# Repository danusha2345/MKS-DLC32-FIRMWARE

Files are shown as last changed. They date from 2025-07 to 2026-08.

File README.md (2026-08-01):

# MKS-DLC32-FIRMWARE — CNC-форк с TMC2209 по UART


Прошивка контроллера **MKS DLC32 v2.1** (ESP32) для ЧПУ-станка со шпинделем:
**без экрана**, с драйверами **TMC2209 в UART-режиме** — ток, микрошаг и тихий
StealthChop настраиваются командами по USB/Wi-Fi, без перемычек и подстроечников.

Форк ветки `MKS-DLC32-NEW-CNC` от [IDLEVEL/MKS-DLC32-FIRMWARE](https://github.com/IDLEVEL/MKS-DLC32-FIRMWARE),
которая основана на брошенной официальной прошивке
[makerbase-mks/MKS-DLC32-FIRMWARE](https://github.com/makerbase-mks/MKS-DLC32-FIRMWARE)
(движок Grbl_ESP32 v1.1). Прошивка переведена на **arduino-esp32 2.0.17**
(espressif32 6.12.0, ESP-IDF 4.4.7) с серией фиксов стабильности — разбор в
[`docs/MIGRATION_6X.md`](docs/MIGRATION_6X.md), технические заметки форка — в
[`docs/FORK_NOTES.md`](docs/FORK_NOTES.md).

## Конфигурация этой ветки

- **Экран не используется.** Станок управляется по USB, Telnet, WebUI в браузере
  или Android-приложением — панель TS35 в этой конфигурации не нужна.
- **TMC2209 по UART**: общая шина на пинах разъёма I2C платы. Из-за этого:
  - выходы **coolant M7/M8 недоступны** (их пины заняты шиной);
  - **внешний пульт IDLEVEL несовместим** с этим вариантом (использует те же IO0/IO4);
  - нужна небольшая **навесная обвязка согласования уровней** (логика драйверов на
    плате пятивольтовая) — см. ниже.
- Шаги идут как обычно (step/dir через I2S-регистры): UART нужен только для
  настройки, при потере связи с драйвером движение не останавливается.

## Целевое железо

- Плата: **MKS DLC32 v2.1** — ESP32-WROOM-32U (8 МБ flash, 520 КБ RAM), степперы
  через I2S-сдвиговые регистры. Полная спека — [`docs/BOARD_SPEC.md`](docs/BOARD_SPEC.md).
- Драйверы: 3× **TMC2209** (степстики) в сокетах платы.
- Назначение: **ЧПУ-фрезер** (3 оси XYZ, шпиндель с PWM).

Карта пинов задаётся в `Firmware/Grbl_Esp32/src/Machines/i2s_out_xyz_mks_dlc32.h`
(флаги `USE_BOARD_V2_0` + `USR_Z_MOTOR` + `USE_TMC2209_UART`):

| Функция | Пин |
|---|---|
| Шпиндель PWM | GPIO32 |
| Probe | GPIO22 |
| Концевики X / Y / Z | GPIO36 / GPIO35 / GPIO34 |
| Степперы X/Y/Z (step/dir) | I2S (BCK16 / WS17 / DATA21) |
| Шина TMC2209 UART | TX=IO0, RX=IO4 (пины разъёма I2C) |
| SD-карта | SPI: SCK14, MISO12, MOSI13, CS15; детект GPIO39 |

Все 3 оси полноценные (движение/джоггинг/probe/обнуление по Z работают).
Авто-хоминг по Z выключен в дефолтах (`$22=0`) — включается через настройки или
`DEFAULT_HOMING_ENABLE 1` + `DEFAULT_HOMING_CYCLE_1 (bit(Z_AXIS))`.

## TMC2209: подключение и настройка

Коротко (полная инструкция с номиналами и граблями —
[`docs/TMC2209_UART.md`](docs/TMC2209_UART.md)):

- ⚠️ **Напрямую проводом подключать нельзя.** На DLC32 логика шаговой части
  пятивольтовая: VIO степстика (пин 7 сокета) жёстко разведён на **+5V**,
  step/dir/en приходят с 74HC595, запитанного 5 В, а EN ещё и подтянут к +5V
  резисторами R31–R33. У TMC2209 порог «1» равен `0.7 × VIO` = **3.5 В** (3.3 В
  с ESP32 недостаточно), а отвечает он уровнем VIO = 5 В — прямо в GPIO ESP32,
  у которого абсолютный максимум ~3.6 В. Нужен преобразователь уровней на одной
  UART-линии: два копеечных буфера с фиксированным направлением (`SN74AHCT1G125`
  с питанием 5 В на TX и `SN74LVC1G17` с питанием 3.3 В на RX — у последнего вход
  толерантен к 5.5 В), либо один `TXU0202`. Плату при этом переделывать не надо.
  Разбор всех вариантов (в том числе почему не годится «перевести VIO на 3.3 В»
  и почему нельзя понизить сам источник 5 В) —
  в [`docs/TMC2209_UART.md`](docs/TMC2209_UART.md).

  ```text
  разъём I2C DLC32                                       общая линия PDN_UART
  (1=+3V3, 2=GND, 3=SDA=IO0, 4=SCL=IO4)
                     ┌────────────────────────┐
   SDA = IO0 (TX) ──►│ SN74AHCT1G125, VCC=+5В │──[1 кОм]──┐
                     │ OE# → GND              │           │
                     └────────────────────────┘           ├───────┬────────┬────────┐
                     ┌────────────────────────┐           │       │        │        │
   SCL = IO4 (RX) ◄──│ SN74LVC1G17, VCC=+3.3В │◄──────────┘   PDN_UART PDN_UART PDN_UART
                     └────────────────────────┘               модуль X модуль Y модуль Z
   GND ── общий                                               (пины RST/SLP сокета)
   +5 В для обвязки — с EXP1 (пин 10), экран не используется
  ```

  На разъёме I2C пин питания — **+3V3, не 5 В**; подключать его никуда не нужно.
- PDN_UART у степстиков SilentStepStick v2.0 выведен на позиции сокета
  **RST/SLP**, а DLC32 соединяет эти два пина между собой и больше никуда —
  провод шины паяется прямо к площадке сокета, ножки отгибать не нужно.
- Шина одна на все три драйвера: адрес получателя прошивка вписывает в каждый
  пакет. Адрес задаётся пинами **MS1/MS2** (в UART-режиме это адресные биты, а не
  микрошаг), которые на DLC32 выведены на штатные DIP-переключатели:

  | Драйвер в сокете | Адрес | Поз. 1 (MS1) | Поз. 2 (MS2) | Поз. 3 |
  |---|---|---|---|---|
  | X (`SW1`) | 0 | OFF | OFF | OFF |
  | Y (`SW2`) | 1 | **ON** | OFF | OFF |
  | Z (`SW3`) | 2 | OFF | **ON** | OFF |

  Позиция 3 — это не MS3, а **SPREAD**: включённая даст SpreadCycle вместо
  StealthChop, держать OFF.

  Принадлежность мотора к оси задаёт **сокет** (step/dir), адрес — только кому
  уйдут настройки тока/микрошага. Перепутанный адрес не поменяет оси местами,
  но настройки «для X» молча применятся к чужому мотору, поэтому: драйвер в
  сокете X обвязывается на адрес 0, в Y — 1, в Z — 2. Два одинаковых адреса =
  оба молчат (CRC-ошибки), прошивка сообщит при старте. Проверка раскладки:
  `$X/Current/Run=0.1` → момент должен потерять именно X-мотор; повторить для Y/Z.
- Настройки в прошивке: ток `$X/Current/Run` (серия `$140`), удержание
  `$X/Current/Hold` (`$150`), микрошаг `$X/Microsteps` (`$160`) — аналогично Y/Z.
  Хранятся в NVS, применяются сразу: можно менять хоть перед каждым заданием.
  `$X/Current/Run=0` отключает выход драйвера (TOFF=0); микрошаг принимается
  только из ряда 0/2/4/8/16/32/64/128/256.
- Режим — StealthChop (тихий), задан на этапе компиляции.
- При старте прошивка проверяет связь с каждым драйвером и пишет результат в
  консоль; предупреждает о short-to-ground и перегреве.

> ⚠️ Вариант TMC2209 UART собран и проверен компиляцией, но **на живом станке
> ещё не гонялся** — базовой прошивки это не касается.

## Сборка

Нужен [PlatformIO Core](https://platformio.org/) (или расширение PlatformIO в VS Code).

```bash
cd Firmware
pio run -e mks_dlc32_v2_1_tmc            # сборка TMC-варианта
pio run -e mks_dlc32_v2_1_tmc -t upload  # прошивка по USB
```

Артефакт: `Firmware/.pio/build/mks_dlc32_v2_1_tmc/firmware.bin`.

Окружения (`Firmware/platformio.ini` + `Firmware/ini/mks_dlc32.ini`):

| env | Назначение |
|---|---|
| `mks_dlc32_v2_1_tmc` | **Основное для этой ветки**: TMC2209 по UART. Партиция `esp32_8MiB.csv` (2× OTA-слота по 3 МБ) |
| `mks_dlc32_v2_1` | Базовый вариант без TMC UART (драйверы в обычном step/dir-режиме, coolant на месте) |
| `mks_dlc32_v2_1_ota` | Загрузка по воздуху (espota, IP в `ini/mks_dlc32.ini`). ⚠️ Собирает **базовый** вариант — для OTA TMC-варианта добавьте в env флаг `-D USE_TMC2209_UART` |

Готовые бинарники в [`release/`](release/) (со скриптами `flash_usb.sh`/`.bat`)
тоже собраны из **базового** варианта — TMC-вариант собирайте из исходников.

## Тесты

Чистую логику (без зависимостей от железа) покрываем нативными unit-тестами:

```bash
cd Firmware
pio test -e native
```

Тесты лежат в `Firmware/test/`, чистая логика — в модулях без зависимостей от
железа, чтобы её можно было гонять нативно:

| Модуль | Тесты | Что покрыто |
|---|---|---|
| `src/SDJobPolicy.cpp` | `test_sd_job_policy` | политика «SD-печать + команды со второго интерфейса» |
| `src/SDLineReader.cpp` | `test_sd_line_reader` | разбор строки G-кода: границы буфера, EOF, ошибка чтения |
| `src/Motors/TrinamicSettings.cpp` | `test_trinamic_settings` | микрошаг вне ряда, деление на ноль в `calc_tstep`, нулевой ток |

Всего 23 теста. Драйверы и `readFileLine` остаются тонкими обёртками над этими
модулями — железо в тестах не участвует.

## Статус

Базовая функциональность **проверена на реальной плате MKS DLC32 v2.1**
(ESP32-D0WD, flash 8 МБ) — протокол испытаний в
[`docs/CODE_REVIEW.md`](docs/CODE_REVIEW.md). Проверка велась на голой плате
(USB): пункты, требующие собранного станка — лимиты/хоминг/движение/джоггинг/
probe/SD-печать со «Стоп» — собраны в
[`docs/MIGRATION_6X.md`](docs/MIGRATION_6X.md#-что-надо-протестировать-на-железе).

- ✅ Собирается на Linux/Mac/Windows.
- ✅ Wi-Fi: событийный авто-реконнект STA, self-heal из AP-fallback, mDNS в AP и
  STA (`http://mks-dlc32.local`). Сеть — WPA2 2.4 ГГц (WPA3-only ESP32 не умеет).
  Ping-soak 60 c = 0% потерь.
- ✅ OTA по воздуху: партиция под реальные 8 МБ, два app-слота по 3 МБ.
- ✅ SD ↔ USB/сеть: во время задания с карты со второго интерфейса проходят
  realtime и read-only запросы (`?`, `$$`, `$G`…), движение отклоняется
  `error:120` **без обрыва задания**.
- ✅ WebUI: канал WebUI↔ядро жив, большие ответы не теряются; имя устройства
  `mks-dlc32`, меняется в WebUI.
- ✅ Telnet, HTTP-загрузка файлов на SD (`/upload`). Карта — только FAT32
  (exFAT не монтируется — карты >32 ГБ переформатировать). Во время задания с SD
  загрузка нового файла намеренно блокируется — заливать до запуска.
- ✅ Удалённое управление через центральный сервер: плата сама подключается к
  нему по TCP (`$Remote/Server`, `$Remote/Token`, `$Remote/Name`, хранятся в
  NVS) — инструкция в [`docs/REMOTE_CONTROL.md`](docs/REMOTE_CONTROL.md).
- ✅ SD-задание честно сообщает о сбое: слишком длинная строка (от 255 символов)
  или ошибка чтения больше не выдаются за успешное завершение; устранена запись
  за границу буфера на строке ровно в 255 символов.
- ✅ Read-only команды (`$$`, `$+`, `$L`, `$S`, `$SC`, `$CMD`) переведены на явный
  `anyState`; `$Axis/Current/Run=0` больше не программирует максимальный ток,
  микрошаг принимается только из ряда 0/2/4…256.
- ⏳ TMC2209 UART: собрано, ждёт проверки на железе (см. выше).
- 🔜 По умолчанию аутентификация выключена — смените пароль AP в WebUI.

## Лицензия

GPLv3 (наследуется от Grbl / Grbl_ESP32). См. [`LICENSE`](LICENSE).

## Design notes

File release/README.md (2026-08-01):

# Прошивка MKS DLC32 v2.1 готовыми бинарниками

Комплект для прошивки платы **без установки PlatformIO** — нужен только Python
с esptool. Версия сборки — в [`VERSION.txt`](VERSION.txt).

| Файл | Что это | Адрес во flash |
|---|---|---|
| `bootloader.bin` | Загрузчик ESP32 (DOUT, 80 МГц) | `0x1000` |
| `partitions.bin` | Таблица разделов под 8 МБ (OTA: два app-слота по 3 МБ) | `0x8000` |
| `boot_app0.bin` | Селектор OTA-слота | `0xe000` |
| `firmware.bin` | Прошивка Grbl_ESP32 + наши фиксы | `0x10000` |
| `spiffs.bin` | Файловая система с WebUI (ESP3D-WEBUI 2.1.3b0, рус./англ.) | `0x610000` |

Настройки платы (**Wi-Fi, `$$`-параметры GRBL**) при прошивке скриптами
`flash_usb.*` **сохраняются** — они лежат в NVS-разделе (`0x9000`), который
скрипты не трогают.

### Единый образ для чистой установки

`MKS_DLC32_full_8MB.bin` (если приложен) — все разделы в одном файле, прошивается
на адрес `0x0`:

```bash
esptool.py --chip esp32 --port /dev/ttyUSB0 --baud 921600 \
  write_flash --flash_mode dout --flash_freq 80m --flash_size 8MB 0x0 MKS_DLC32_full_8MB.bin
```

Удобен для веб-флешеров (ESP Web Tools, MKS Flash Tool). **Внимание:** этот образ
перезаписывает NVS → **настройки Wi-Fi сбрасываются** (плата поднимет точку доступа
`MKS_DLC`). Чтобы сохранить настройки — прошивайте раздельными bin через `flash_usb.*`.

## Подготовка (один раз)

1. **Python 3** — [python.org](https://www.python.org/downloads/) (Windows: при
   установке отметить «Add Python to PATH»).
2. **esptool**: `pip install esptool`
3. **Windows**: драйвер USB-моста [CH340](https://www.wch-ic.com/downloads/CH341SER_EXE.html).
   Номер порта смотреть в Диспетчере устройств → «Порты (COM и LPT)».
   **Linux**: пользователь должен быть в группе `dialout`
   (`sudo usermod -aG dialout $USER`, перелогиниться).

## Прошивка по USB

Подключить плату кабелем USB (питание платы 12/24 В подавать не обязательно —
для прошивки хватает USB).

**Linux/macOS:**
```bash
./flash_usb.sh                 # порт /dev/ttyUSB0
./flash_usb.sh /dev/ttyUSB1    # другой порт
```

**Windows:**
```bat
flash_usb.bat            (порт COM3)
flash_usb.bat COM5       (другой порт)
```

Если на скорости 921600 прошивка обрывается (длинный/плохой кабель), добавить
вторым аргументом `115200`.

### Полный сброс (если плата вела себя странно или стояла другая прошивка)

Стереть всё, включая настройки, затем прошить:

```bash
esptool.py --chip esp32 --port /dev/ttyUSB0 erase_flash
./flash_usb.sh
```

После этого плата поднимет точку доступа `MKS_DLC` (пароль `12345678`),
веб-интерфейс: `http://192.168.4.1`. Подключение к домашней сети — в
WebUI → Settings (сеть должна быть **WPA2, 2.4 ГГц** — WPA3-only ESP32 не умеет).

## Обновление по воздуху (OTA), когда плата уже в сети

Из дерева исходников (нужен PlatformIO):

```bash
pio run -e mks_dlc32_v2_1_ota -t upload --upload-port <IP-платы>
```

Только WebUI (SPIFFS): `pio run -e mks_dlc32_v2_1 -t uploadfs` по USB.

## Откуда взялись бинарники

Собраны из этого репозитория: `pio run -e mks_dlc32_v2_1_tmc` (+`-t buildfs` для
SPIFFS); `bootloader.bin`/`boot_app0.bin` — стандартные из arduino-esp32 1.0.6
(`bootloader_dout_80m.bin`). Адреса соответствуют тому, что пишет
`pio run -t upload` (проверено `-v`).

> ⚠️ **Это сборка варианта `mks_dlc32_v2_1_tmc`** — драйверы TMC2209 настраиваются
> по UART, экран не используется, coolant M7/M8 недоступен (его пины заняты шиной).
> Шине нужна навесная обвязка согласования уровней: логика драйверов на плате
> пятивольтовая, ESP32 — 3.3 В. Схема, номиналы и обоснование —
> [`docs/TMC2209_UART.md`](../docs/TMC2209_UART.md). **Без обвязки UART не заработает,
> а RX, заведённый напрямую, способен повредить GPIO ESP32.** Сам станок при этом
> ездит как обычно: step/dir идут через I2S и от UART не зависят.
> На живом станке эта сборка ещё не проверялась.

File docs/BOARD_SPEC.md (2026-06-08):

# MKS DLC32 v2.1 — аппаратная спецификация (справочник)

Сводка характеристик платы, вытянутая из официальных источников. Нужна как справка
при доработке прошивки (особенно по flash/OTA и связи).

## Процессор / память
- **Модуль:** ESP32-WROOM-32U (чип ESP32-D0WD-V3, Xtensa dual-core LX6, до **240 MHz**).
- **Flash: 8 МБ** (8192 КБ). ⚠️ Не 16 МБ — важно для разбивки разделов и OTA.
- **RAM:** 520 КБ SRAM.
- Беспроводь: Wi-Fi (2.4 ГГц) + Bluetooth — встроены в ESP32. **Проводного Ethernet нет.**

## Связь
- **Wi-Fi:** AP или STA, WebUI / WebSocket / Telnet / OTA / mDNS.
- **USB:** через USB-UART (CH340) — управление с ПК и прошивка. Не сеть.
- **Bluetooth:** аппаратно есть (в прошивке `ENABLE_BLUETOOTH` выкл; есть подпроект `GRBL_Bluetooth/`).
- **SD-карта:** локальное хранилище/запуск G-code.
- **Ethernet/RJ45: отсутствует.**

## Управление / экран
- 3 оси (XYZ).
- Экран: тач-TFT **MKS TS35 (3.5")** или **TS24** (V2.0).
- Драйверы шагов: **TMC2209** (штатно), также A4988 / DRV8825, поддержка внешних драйверов.
- Степперы заводятся через I2S-сдвиговые регистры (см. `i2s_out_xyz_mks_dlc32.h`).
- Выход шпинделя/лазера: PWM (в прошивке GPIO32).
- Макс. скорость перемещения: **до 8000 мм/мин**.

## Питание / габариты
- Вход: **DC 12 В или 24 В**, ток < 10 A.
- Размер платы: **90 × 70 мм**.

## Софт
- Прошивка: GRBL (Grbl_ESP32). Хосты: LightBurn, LaserGRBL, UGS и т.п.
- Управление: экран (офлайн) / WebUI / мобильное приложение.

## Версии
- Линейка: V1.0 / V2.0 / V2.1. У нас **V2.1** (в прошивке флаг `USE_BOARD_V2_0` для пин-маппинга,
  машина `MACHINE_TYPE_DEFAULT`). Есть и отдельная новая плата **DLC32 MAX** на ESP32-S3 — это другое железо.

## Следствия для прошивки (важно)
- **OTA:** при 8 МБ flash партиция `esp32_16MiB.csv` (env `mks_dlc32_v2_1_ota`) **не подходит** —
  нужна OTA-разбивка под 8 МБ (два app-раздела ~3 МБ + SPIFFS). Текущий рабочий env —
  `mks_dlc32_v2_1` (4 МБ layout, USB), и он в 8 МБ укладывается.
- Прошивка сейчас занимает Flash ~94% от ~1.79 МБ app-раздела — для OTA на 8 МБ места хватит,
  но app-раздел в OTA-схеме надо задать с запасом.

## Источники
- [makerbase-mks/MKS-DLC32 (офиц. репозиторий, hardware/доки/схемы)](https://github.com/makerbase-mks/MKS-DLC32)
- [MKS DLC32 V2.1 Offline Controller User Manual (manuals.plus)](https://manuals.plus/ae/1005004617130208)
- [MKS DLC32 V2.1 SCH.pdf — схема платы](https://github.com/makerbase-mks/MKS-DLC32/blob/main/MKS-DLC32-main/hardware/MKS%20DLC32%20V2.1_003/MKS%20DLC32%20V2.1_003%20SCH.pdf)

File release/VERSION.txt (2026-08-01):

Сборка: feat/tmc2209-uart 9eb311e, дата 2026-08-01, предрелиз v2.1-tmc-beta4
Вариант: mks_dlc32_v2_1_tmc — TMC2209 по UART, БЕЗ экрана
Прошивка: Grbl_ESP32 1.1 (2022042101) + фиксы форка danusha2345
SDK: arduino-esp32 2.0.17 (espressif32 6.12.0, ESP-IDF 4.4.7)
WebUI: ESP3D-WEBUI 2.1.3b0 (en/ru/uk/de/fr/es/it/pl/ptbr)
Плата: MKS DLC32 v2.1, ESP32-WROOM-32U, 8 МБ flash

!! ПРЕДРЕЛИЗ. На живом станке эта сборка не проверялась.
!! TMC2209 по UART требует навесной обвязки согласования уровней:
!! логика драйверов на плате пятивольтовая, ESP32 — 3.3 В.
!! Схема и номиналы: docs/TMC2209_UART.md. Без обвязки шина не заработает
!! (а RX напрямую способен повредить GPIO ESP32).

Новое в v2.1-tmc-beta4:
  - $Axis/Current/Run=0 теперь действительно отключает выход драйвера
    (TOFF=0, мосты обесточены). В beta3 писался только IRUN=IHOLD=0, что
    по даташиту TMC2209 означает минимальный ток (1/32 шкалы, ~55 мА RMS),
    а не ноль.
  - Bare-board smoke-тест на живой плате: загрузка с GPIO0-как-TX, три
    честных «driver test failed» без драйверов, SD-фиксы (TooLong/Finish/
    восстановление после сбоя), валидация Microsteps с persistence через
    ребут — PASS. С реальными драйверами и обвязкой уровней не проверялось.

Новое в v2.1-tmc-beta3 (все фиксы v1.3.0 базовой ветки + доводка):
  - SD-печать честно сообщает о сбое (TooLong/ReadError вместо ложного
    "SD Print Finish!"), нет записи за границу буфера, SD не виснет в Busy
    после выёма карты, закрыта гонка ?-статуса с закрытием файла.
  - StallGuard-хоминг не роняет плату при Microsteps=0.
  - $Axis/Microsteps: значения вне ряда 0/2/4...256 отклоняются и в NVS
    не попадают.
  - 23 нативных unit-теста.

Новое в v2.1-tmc-beta2:
  $Axis/Current/Run=0 = выключенный ток; SENDDELAY=2; разбор уровней
  TMC2209 <-> DLC32 в docs/TMC2209_UART.md.

Новое в v2.1-tmc-beta1:
  Вариант прошивки с TMC2209 по UART: ток, микрошаг и StealthChop
  настраиваются командами; шаги идут как обычно через I2S. Экран не
  используется, coolant M7/M8 недоступен (его пины заняты шиной).

Файлы:
  MKS_DLC32_full_8MB.bin  - единый образ на 0x0 (чистая установка, сброс Wi-Fi)
  firmware.bin + spiffs.bin + bootloader/partitions/boot_app0
  flash_usb.sh / flash_usb.bat - прошивка с сохранением настроек

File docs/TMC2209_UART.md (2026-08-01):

# TMC2209 в UART-режиме на MKS DLC32

Вариант прошивки `mks_dlc32_v2_1_tmc`: драйверы TMC2209 управляются шагами как обычно
(step/dir через I2S-регистр), а по UART настраиваются ток, микрошаг и StealthChop —
в любой момент, в том числе перед каждым заданием.

## Сборка и прошивка

```bash
cd Firmware
pio run -e mks_dlc32_v2_1_tmc            # сборка
pio run -e mks_dlc32_v2_1_tmc -t upload  # прошивка по USB
```

Обычный env `mks_dlc32_v2_1` не затронут: без флага `USE_TMC2209_UART` прошивка
идентична прежней (step/dir, coolant на месте).

## ⚠️ Уровни: голым проводом подключать нельзя

Это главный подводный камень варианта. Всё, что ниже, сверено с официальной схемой
[MKS DLC32 V2.1_003 SCH.pdf](https://github.com/makerbase-mks/MKS-DLC32/blob/main/MKS-DLC32-main/hardware/MKS%20DLC32%20V2.1_003/MKS%20DLC32%20V2.1_003%20SCH.pdf)
и даташитом TMC2209 (rev. 1.03).

Логическая часть шаговой обвязки DLC32 работает **на 5 В**, а ESP32 — на 3.3 В:

| Что | Напряжение | Где на схеме |
|---|---|---|
| VIO степстика (пин 7 сокета, `VDD`) | **+5V**, жёстко разведено | `DRIVE.sch`, `J24/J25/J26` |
| STEP / DIR / EN | 5 В, с 74HC595 (`U3`, VCC=+5V) через сборки RPK | `ESP32.sch` + `DRIVE.sch` |
| Подтяжки EN | на **+5V** (`R31/R32/R33`) — присутствуют всегда, даже до старта прошивки | `DRIVE.sch` |
| MS1/MS2/MS3 | DIP-переключатели коммутируют на **+5V** | `DRIVE.sch`, `SW1/SW2/SW3` |
| GPIO ESP32 | 3.3 В, абсолютный максимум ~3.6 В | `ESP32.sch` |

Из даташита TMC2209: `VINHI = 0.7 × VVIO`, то есть при VIO = 5 В порог логической «1»
равен **3.5 В** — трёх с третью вольт с ESP32 недостаточно по спецификации. А PDN_UART
описан как «I/O with Schmitt Trigger and **VCC_IO level**», то есть ответ драйвера
идёт уровнем 5 В — прямо в GPIO ESP32, чего тот не переживёт.

Итог: **нужен преобразователь уровней на UART-линии.** Одна логическая микросхема и
три резистора — переделывать саму плату не нужно.

### Схема согласования

Два однобитных буфера с фиксированным направлением — по одному на каждую сторону
полудуплексной линии:

```text
разъём I2C DLC32               навесная обвязка                общая линия PDN_UART
(пины: 1=+3V3, 2=GND,
 3=SDA=IO0, 4=SCL=IO4)
                       ┌───────────────────────┐
  SDA (IO0, TX) ──────►│ SN74AHCT1G125, VCC=+5В│──[1 кОм]──┐
                       │ OE# → GND             │           │
                       └───────────────────────┘           ├────┬────────┬────────┐
                       ┌───────────────────────┐           │    │        │        │
  SCL (IO4, RX) ◄──────│ SN74LVC1G17, VCC=+3.3В│◄──────────┘ PDN_UART PDN_UART PDN_UART
                       └───────────────────────┘             модуль X модуль Y модуль Z
  GND ── общий с платой и с обвязкой                        (пины RST/SLP сокета)
  по 100 нФ на каждое питание, рядом с корпусом
```

- **TX: `SN74AHCT1G125`** (SOT-23-5) питается от **+5 В**: у HCT-логики порог входа
  ~1.3 В, поэтому 3.3 В с ESP32 — уверенная «1», а на выходе получаются честные 5 В для
  входа TMC2209. `OE#` (пин 1) на GND. Такой буфер прямо предложен даташитом TMC2209
  (Fig. 4.2, «optional buffer for … many slaves»).
- **Резистор 1 кОм** — как в даташите (Fig. 4.1): мастер держит линию постоянно, и когда
  драйвер отвечает нулём, резистор ограничивает встречный ток (5 В / 1 кОм = 5 мА). Если
  связь с тремя драйверами неустойчива — уменьшить до ~470 Ом.
- **RX: `SN74LVC1G17`** (Schmitt-буфер, SOT-23-5) питается от **+3.3 В**, но его вход
  толерантен к 5.5 В — то есть принимает пятивольтовый ответ драйвера и отдаёт чистые
  3.3 В в ESP32. Резистивный делитель тут хуже: он вешает на шину лишнюю нагрузку на
  землю и заваливает фронты.
- **Питание обвязки**: экран в этой ветке не используется, поэтому свободен разъём
  **EXP1: пин 10 = +5V, пин 9 = GND** (`P-AUX.sch`). +3.3 В — пин 1 разъёма I2C или
  пин 10 EXP2. Альтернатива для 5 В — пин 7 (VDD) любого степстик-сокета.

**Однокристальная альтернатива — `TXU0202`** (TI): два канала с фиксированными встречными
направлениями, dual-rail 3.3 / 5 В, push-pull выходы, Schmitt-входы. Подключение то же:
`A1←TX`, `B1─[1 кОм]→линия`, `B2←линия`, `A2→RX`, `OE` на 3.3 В, по 100 нФ на VCCA и VCCB.
Брать корпус **VSSOP (суффикс DCU)** — варианты X2SON/X1QFN вручную не паяются. Учесть,
что у TXU0202 на входах есть внутренние pull-down: пока VCCA/OE не поднялись, линия PDN
провисает в ноль (для драйверов это штатный standstill current reduction, но до первого
пакета они будут в нём). У пары 1G125 + 1G17 линия встаёт в idle-high сразу с питанием.
- ⚠️ **На разъёме I2C пин питания — +3V3, а не 5 В** (по схеме `J2` пин 1 = `+3V3`).
  Для питания буфера он не годится, и вообще на этот разъём ничего подавать не нужно.

### Почему нельзя «просто перевести VIO драйверов на 3.3 В»

Абсолютный максимум цифрового входа TMC2209 — `VVIO + 0.5 В`. Если сделать VIO = 3.3 В,
то EN, STEP и DIR (все они пятивольтовые, см. таблицу выше) начнут пробивать защитные
диоды внутрь шины VIO. На EN ток потечёт **постоянно**, из-за подтяжки R31 на +5 В — она
неотключаемая. Насколько быстро это убьёт драйвер, зависит от номинала сборок RPK.

Чтобы этот путь заработал, пришлось бы отогнуть у каждого модуля VDD, EN, STEP и DIR
(12 ножек на три оси) и подать сигналы через понижающий буфер 74LVC245 — то есть намного
больше работы, чем один вентиль на одном проводе.

### Почему нельзя понизить сам источник 5 В

Тоже нет: на DLC32 3.3 В **делаются из 5 В**. Бука `U4` даёт +5V, из него LDO `U5`
получает +3V3 для ESP32 (`POWER.sch`). Понизив +5V, получим LDO в dropout и мёртвый
ESP32. А закоротить LDO нельзя, потому что при питании от USB 5 В приходит на тот же
рейл в обход буки (`U5V → D3 → +5V`) — при первом подключении кабеля 5 В попадут на
ESP32. Плюс от +5V питаются разъёмы концевиков `J9…J12` (для активных датчиков).

Теоретически возможен третий путь — **локальный 3.3-вольтовый домен**: перекинуть на
+3V3 питание `U3` (пины 16 и 10), VDD трёх сокетов, верхние концы `R31…R33` и общий
провод DIP-переключателей. Тогда весь тракт становится 3.3-вольтовым и UART подключается
напрямую. Но это 7–8 точек SMD-хирургии, необратимо, и надо иметь в виду, что BCK шины
I2S здесь 8 МГц (`I2S_OUT_USEC_PER_PULSE = 4` мкс на 32-битный кадр) — у 74HC595 при
питании 3.3 В запас по частоте перестаёт быть многократным.

## Проводка

UART-шина сидит на пинах **разъёма I2C** платы (паяться к ESP32 не нужно):

| Сигнал | Пин ESP32 | Куда |
|---|---|---|
| TX | IO0 (пин 3 разъёма I2C, шелкография `SDA`) | на вход буфера 74AHCT1G125 |
| RX | IO4 (пин 4 разъёма I2C, шелкография `SCL`) | на среднюю точку делителя 10к/20к |
| GND | пин 2 разъёма I2C | общий с обвязкой (с драйверами уже общий через плату) |

Перед пайкой прозвонить разъём: пин с шелкографией **SDA** должен звониться на
GPIO0 модуля ESP32, **SCL** — на GPIO4 (в прошивке `IIC_SDA=0`, `IIC_SCL=4`).

**Куда паять PDN_UART.** У степстиков SilentStepStick TMC2209 v2.0 (Watterott, FYSETC и
клоны) PDN_UART выведен на **две позиции сокета — `RST` и `SLP`** (пины 12 и 11), выбор
джампером на модуле. На DLC32 эти два пина сокета **соединены между собой и больше
никуда не идут** — изолированный островок. Поэтому провод шины паяется прямо к площадке
`RST`/`SLP` сокета, **ножки модулей отгибать не нужно**.

У модулей BTT (TMC2209 v1.2 и родня) разводка своя — там отдельный UART-пятак на плате
модуля; проверить прозвонкой и паять к нему.

## Адреса драйверов (штатными DIP-переключателями)

В UART-режиме MS1/MS2 задают не микрошаг, а адрес на шине. На DLC32 они выведены на
DIP-переключатели `SW1` (X), `SW2` (Y), `SW3` (Z), которые коммутируют их на +5 В = VIO —
то есть адреса выставляются переключателями, ничего допаивать не нужно:

| Ось | Адрес | Поз. 1 (MS1) | Поз. 2 (MS2) | Поз. 3 |
|---|---|---|---|---|
| X | 0 | OFF | OFF | OFF |
| Y | 1 | **ON** | OFF | OFF |
| Z | 2 | OFF | **ON** | OFF |

⚠️ **Позиция 3 DIP — это не MS3, а `SPREAD`** (у SilentStepStick в позиции сокета `MS3`
стоит именно SPREAD). Включённая позиция 3 = SpreadCycle вместо StealthChop. Держать OFF.

Микрошаг задаётся прошивкой (по умолчанию 16, настройка `$Axis/Microsteps`).

Принадлежность мотора к оси определяет **сокет** (step/dir идут по плате), адрес — лишь
то, кому уйдут настройки тока и микрошага. Два одинаковых адреса = оба драйвера молчат
(CRC-ошибки), прошивка сообщит при старте.

## Что меняется в прошивке

- Ток: по умолчанию run 0.8 А / hold 0.4 А (RMS), настройки `$X/Current/Run`
  (=$140-серия), `$X/Current/Hold` ($150), микрошаг `$X/Microsteps` ($160) —
  аналогично Y/Z; сохраняются в NVS, применяются сразу (можно менять перед
  каждым заданием по USB/Telnet/WebUI).
  `$X/Current/Run=0` **отключает выход драйвера** (TOFF=0, мосты обесточены; IRUN=0 без
  этого был бы 1/32 шкалы), а не программирует максимальный ток.
- Микрошаг принимается только из ряда, который понимает драйвер: 0 (полный шаг), 2, 4, 8,
  16, 32, 64, 128, 256. Остальные значения не применяются, в консоль идёт предупреждение.
- `SENDDELAY=2` выставляется каждому драйверу при старте — требование даташита для шины
  с несколькими слейвами.
- Режим: StealthChop (тихий), задан на этапе компиляции
  (`TRINAMIC_UART_RUN_MODE` в machine-файле).
- Диагностика: при старте драйвер проверяет связь по UART и пишет в консоль
  результат; при проблемах (short to ground, перегрев) — warning. Если UART
  не отвечает, шаги всё равно работают (step/dir независимы).
- **Coolant (M7/M8) недоступен** — его пины (IO0/IO4 на разъёме I2C) заняты шиной.
  Если нужен air assist по M8 — этот вариант прошивки не подходит без переноса пина.

## Ограничения

- Sensorless homing (StallGuard) не включён: для него нужно дополнительно завести
  выход DIAG каждого драйвера на вход соответствующего концевика.
- IO0 — strapping-пин ESP32. На самой плате он подтянут к +3V3 (`R4`), а PDN_UART у
  TMC2209 не имеет внутренней подтяжки (в даташите он `DIO`, без пометки `pd`), так что
  загрузке шина не мешает. С буфером на TX линия PDN и вовсе развязана от IO0 —
  ESP32 видит только вход логики. Но правило прежнее: не вешать на IO0 ничего лишнего,
  особенно того, что может держать его в нуле при сбросе.

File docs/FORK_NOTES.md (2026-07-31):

# FORK_NOTES — технический разбор и дорожная карта

Рабочие заметки по форку прошивки MKS DLC32 v2.1 под ЧПУ. Назначение — чтобы при
дальнейшей доработке не переоткрывать заново контекст.

## Происхождение

```
makerbase-mks/MKS-DLC32-FIRMWARE   (Grbl_ESP32 v1.1, build 2022042101, заброшен 2023-01)
        └── IDLEVEL/MKS-DLC32-FIRMWARE  (ветка MKS-DLC32-NEW-CNC, CNC-доработки)
                └── ЭТОТ ФОРК (danusha2345), ветка MKS-DLC32-NEW-CNC
```

Remotes: `origin` = форк, `upstream` = IDLEVEL, `makerbase` = оригинал (для диффов).

Почему именно IDLEVEL: из всех форков только он развивает CNC-направление (у `01power`
— лазер/CoreXY). Минусы IDLEVEL, которые правим: не собирался на Linux, бессмысленные
сообщения коммитов, ~236 МБ мусора (KiCad/G-code) в `PCB/`, код стороннего железа
включён по умолчанию.

## Что IDLEVEL добавил поверх оригинала

- **OTA** (обновление по воздуху): env `mks_dlc32_v2_1_ota`, партиция `esp32_16MiB.csv`,
  заливка через `espota` на 192.168.4.1.
- **ExternalBoard** — выносной пульт на ёмкостных кнопках `Adafruit_MPR121`, связь по
  UART1 (Zero/Home/Probe). Пины по умолчанию GPIO 4/0 (= IIC шины платы).
- **I2C** (`I2C.cpp`) — generic-обёртка, фактически мёртвый код (никто не вызывает,
  `Uart1` нигде не используется, к OTA-флагу `USE_UART_I2C_PINS` отношения не имеет —
  тот работает через `Uart0`).
- **SDCardWriter** — приём gcode в файл `/TEMP.GCODE` на SD (для загрузки по сети).
- **Telnet** переписан (`TelnetServerClient`, нормальный сетевой стрим).
- Отдельные проекты: `Joystick/` (беспроводной пульт), `GRBL_Bluetooth/` (BT-мост).
- Переход на C++17.

## Сделано в этом форке

1. **Починена сборка на Linux** — `ExternalBoard.cpp` содержал
   `#include "mks\MKS_draw_move.h"` с обратным слешом (Windows-only) → заменено на `/`.
   После этого `pio run -e mks_dlc32_v2_1` собирается (Flash ~94%).
2. **Гигиена репозитория** — удалён закоммиченный build-артефакт
   `Grbl_Esp32.ino.cpp` (содержал захардкоженные пути `C:\Users\Sergey\...`),
   добавлен `.gitignore` (`.pio/`, `.claude/`, `*.ino.cpp`).
3. **Внешний пульт → компайл-тайм переключатель.** `ExternalBoard.cpp` и `I2C.cpp`
   обёрнуты в `#ifdef ENABLE_EXTERNAL_BOARD`; мастер-флаг в `Config.h` по умолчанию
   выключен. GitNexus `impact(ExternalBoard)` подтвердил: класс импортируется только
   3 файлами (Protocol.cpp, Grbl.cpp, ExternalBoard.cpp), все под guard → risk LOW.
   Проверено сборкой в обе стороны:
   - OFF (дефолт): Flash 94.0% (1 724 042 б), MPR121 не линкуется.
   - ON (`-DENABLE_EXTERNAL_BOARD`): Flash 94.2% (1 728 954 б), пульт возвращается.
4. **OTA-партиция под реальные 8 МБ.** Создан `esp32_8MiB.csv` (2× app по 3 МБ + SPIFFS),
   в `ini` оба env переведены на него + `board_*.flash_size = 8MB`; из OTA-env убран
   `USE_UART_I2C_PINS` (уводил консольный Uart0 на GPIO0/4). Раньше OTA-env брал
   `esp32_16MiB.csv`, не влезавший в 8 МБ. Теперь USB- и OTA-сборки на одной таблице
   разделов → бинарник идентичен, плата после USB-прошивки сразу OTA-совместима.
   Проверено сборкой обоих env: Flash 54.8% (1 724 042 б из 3 МБ-слота).
5. **SD ↔ USB вместе — read-only запросы во время печати с карты.** Раньше во время
   job с SD char-гейт в `Serial.cpp` дропал любой ввод с USB/сети и слал
   `error: AnotherInterfaceBusy` на каждую строку. Теперь:
   - `Serial.cpp` всегда буферизует символы (realtime `?`/`!`/`~`/сброс и так проходили
     до гейта — мониторинг/пауза/резюм по USB во время печати работали и раньше);
   - решение принимается на уровне готовой строки в `Protocol.cpp` через чистый
     классификатор `line_safe_during_sd_job()` (`SDJobPolicy.{h,cpp}`): read-only
     запросы (`$$ $# $G $I $N $`) и пустые строки выполняются, любое движение/исполнение
     и запись настроек — отклоняются с `AnotherInterfaceBusy`.
   - Зачем: хост (LightBurn/UGS/WebUI) по USB может опрашивать состояние прямо во время
     гравировки с карты, не рискуя смешать два потока G-кода в планировщике.
   - Классификатор покрыт **нативными тестами** (`test/test_sd_job_policy/`, `pio test -e native`,
     5/5 PASSED). Поведение на железе ещё проверить.
6. **WebUI: оживлён канал WebUI↔ядро (issue #25).** Корень зависания вкладки настроек —
   в `Config.h` были выключены `ENABLE_SERIAL2SOCKET_IN/OUT`. Из-за этого GRBL-команды
   из WebUI (`$$`, jog, смена hostname) пушились в `Serial2Socket`, но не читались
   (вход, Serial.cpp:166) и ответы не уходили в WebSocket (выход, Serial.cpp:367) —
   `[ESP…]` (синхронный HTTP) работали, а всё GRBL — нет, вкладка настроек висела вечно.
   Сама реализация `Serial2Socket` (ring-буферы, flush, `broadcastBIN`, `attachWS`) полная —
   просто отключена флагами. Включил оба → собирается (Flash 54.8%). Плюс дефолтный
   `DEFAULT_HOSTNAME` теперь `mks-dlc32` (имя устройства/mDNS; меняется в настройках WebUI).
   Нужна проверка на железе. (MACHINE_NAME/BOARD_NAME — compile-time, только инфо.)

## Заметки по плате (стоковая DLC32 v2.1 + TS35)

- Машина: `MACHINE_TYPE_DEFAULT` → `Machines/i2s_out_xyz_mks_dlc32.h`.
- `N_AXIS = 3`, `USE_BOARD_V2_0` и `USR_Z_MOTOR` определены.
- Шпиндель/лазер PWM = **GPIO32** (см. issue #45 оригинала про PWM), probe = GPIO22,
  Z-концевик = GPIO34.
- Ось Z полноценная (движение/джоггинг/probe/обнуление в UI `MKS_draw_move.cpp`).
  Z-хоминг выключен в дефолтах (DLC32 продаётся «лазерным», концевика часто нет).
- Flash платы = **8 МБ** (ESP32-WROOM-32U), см. [`BOARD_SPEC.md`](BOARD_SPEC.md). Партиция
  `esp32_8MiB.csv`: app-слот 3 МБ, прошивка ~55% — запас под фичи есть.

## Дорожная карта / TODO

Приоритет по запросам пользователя и багам оригинала:

1. **Удалённое подключение — ✅ ГОТОВО, валидировано на реальной плате**
   (протокол испытаний — в [`CODE_REVIEW.md`](CODE_REVIEW.md), раздел «Валидация на железе»):
   - [x] OTA-партиция под 8 МБ (`esp32_8MiB.csv`); OTA по воздуху проверена —
         заливка espota за ~51 с, загрузка из второго слота, STA переподключается.
   - [x] Реконнект STA: `setAutoReconnect` оказался no-op в ядре 1.0.6 — заменён
         явным `WiFi.reconnect()` раз в 15 с в `WiFiConfig::handle()` с guard'ом
         `sta_connect_busy` (без него конкурентный reconnect вешал clientCheckTask —
         найдено на железе).
   - [x] mDNS в AP и STA (`http://mks-dlc32.local` резолвится с хоста); HTTP-сервис
         `_http._tcp` регистрируется в обоих режимах.
   - [x] Issue #25 (вкладка настроек WebUI): включены `ENABLE_SERIAL2SOCKET_IN/OUT`,
         TX-путь Serial2Socket переписан на мьютекс (lossless + фикс use-after-free
         при выключении Wi-Fi). `$$` приходит в WebUI целиком — проверено по WS.
   - [x] Дефолтное имя устройства `mks-dlc32` (вместо `grblesp`); меняется в WebUI.
   - [x] Telnet :23 — `$I`/`$$`/realtime работают.
2. **SD ↔ USB одновременно — ✅ ГОТОВО, валидировано на плате**: во время печати
   с карты `?`/`$$`/`$G` со второго интерфейса проходят, `G0` отклоняется
   `error:120` без обрыва печати, файл доходит до `SD Print Finish!`.
   Карта обязана быть FAT32 (exFAT ядро 1.0.6 не понимает; детект — GPIO39).
   - **HTTP-загрузка на SD (`/upload`) перепроверена на плате 2026-06-11** по
     жалобе заказчика «файл не загружается на карту»: малый файл, 1.2 МБ,
     сразу после старта платы, после завершения SD-задания — везде ✅.
     Единственный падающий сценарий — **загрузка во время выполнения задания
     с SD**: отклоняется намеренно (карта на SPI занята чтением G-code,
     запись оборвала бы рез). Это не баг, но см. TODO ниже.
   - [ ] TODO: при загрузке во время SD-задания плата обрывает соединение и
     отдаёт **пустой HTTP-ответ** вместо `{"status":"Busy"}` — клиент видит
     молчаливый сбой. Стоит отдавать честный Busy, чтобы приложение могло
     показать «станок занят».
3. ~~**Фикс языка экрана.**~~ Сделано (PR #3): присваивания вместо `==` убраны,
   английская таблица заполняется явно, мёртвое чтение `$40` из `mks_grbl_parg_init()` удалено.
   Экранные обработчики выбора языка не трогали — в конфигурации без экрана они недостижимы.
4. (Опц.) Безопасность: `ENABLE_AUTHENTICATION` выключен — сменить пароль AP в WebUI.
5. (Опц.) Z-хоминг под станок с концевиком — включить в дефолтах или документировать `$22`.
6. (Опц.) Почистить `PCB/` (236 МБ KiCad/G-code) из истории, если не нужен.

## WebUI: обновлённый билд и рецепт пересборки

В `data/index.html.gz` теперь свежий **ESP3D-WEBUI v2.1.3b0** (был старый 2.1b68 от MKS):
паузa/резюм SD-печати из веба, полный набор GRBL-оверрайдов (подача/ускоренные/шпиндель,
реалтайм 0x90–0x9D), русский язык интерфейса (выбирается в Settings → Interface Language),
заголовок «MKS DLC32 — ESP3D WebUI». Ссылки в меню исправлены: «Firmware» ведёт на наш
репозиторий (вместо заброшенного bdring/Grbl_Esp32), «Interface» — на ветку 2.1
ESP3D-WEBUI (главная репозитория — уже про несовместимый v3, он под ESP3D 3.x).
Проверено на плате: страница отдаётся, WS-канал жив.

Пересборка из исходников:

```bash
git clone --depth 1 -b 2.1 https://github.com/luc-github/ESP3D-WEBUI
cd ESP3D-WEBUI
# правки UI — в www/ (index.html, js/grbl.js, css/…)
npm install && npm install -D gulp@4   # gulp 5 из package.json ломается на старых плагинах
npx gulp package --lang grbl           # языковой набор: en/ru/uk/de/fr/es/it/pl/ptbr
cp index.html.gz <форк>/Firmware/Grbl_Esp32/data/
pio run -e mks_dlc32_v2_1 -t uploadfs  # залить SPIFFS на плату
```

## Релевантные issues оригинала (makerbase, у IDLEVEL issues отключены)

| # | Тема |
|---|---|
| 55 | Шпиндель не держит верхний лимит оборотов |
| 51 | Ошибка позиции при обработке дуг G2/G3 |
| 48 | M05 подвешивает программу |
| 45 | В lasermode `$32=1` нет PWM на GPIO32 |
| 28 | Interface I2C (IDLEVEL добавил) |
| 23 | Длинные имена файлов перетирают X/Y при гравировке с SD |
| 21 | «Есть ли улучшенный форк, которым реально пользуются» |

## Навигация по коду

Репозиторий проиндексирован **GitNexus** (имя графа `MKS-DLC32-FIRMWARE`).
Для исследования/impact-анализа использовать инструменты GitNexus (`query`, `context`,
`impact`), а не только grep — граф ловит связи, которые текстовый поиск пропускает.

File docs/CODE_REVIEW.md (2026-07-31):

# Code review — ревизия правок форка и кода

> Документ в двух частях: первый проход (ревью всех правок + кода) и
> второй проход (перепроверка самих ревью-фиксов). Итог второго прохода — внизу.

Многоагентное адверсариальное ревью (6 дименшенов × 2 верификатора на находку +
critic полноты). Ниже — что подтвердилось, что исправлено, что отложено и что отсеяно.

Контекст, который агенты не учли (проверено вручную):
**`ENABLE_SD_CARD` ВКЛЮЧЁН.** Машинный хедер `i2s_out_xyz_mks_dlc32.h` делает `#undef ENABLE_SD_CARD`,
но он подключается из `Config.h:66` — *раньше* `#define ENABLE_SD_CARD` (строка 101), поэтому
`#undef` срабатывает вхолостую. Эмпирически: символы `set_sd_state/closeFile/readFileLine`
присутствуют в `firmware.elf`. Значит SD-путь жив, и регрессия #1/#2 достижима.

## ✅ Исправлено (коммит ревью)

1. **РЕГРЕССИЯ (наша): отклонение/выполнение строки 2-го интерфейса во время SD-печати
   обрывало печать.** `Protocol.cpp`: рейзилось через `report_status_message()`, который при
   `BusyPrinting` на любой не-Ok-ошибке делает `closeFile()` (обрыв), а на Ok — ставит
   `SD_ready_next` (двойная прокрутка SD-потока). Переписан SD-гейт: строки 2-го интерфейса
   во время печати квитируются НАПРЯМУЮ (`grbl_send "ok"`/`grbl_sendf "error:N"`), минуя
   SD-логику. Read-only запросы выполняются, движение отклоняется — печать не страдает.
2. **Авто-дизейбл степперов — тавтология `||` (моторы отключались даже в Hold).**
   `Protocol.cpp`: `if((sys.state != Cycle) || (sys.state != Hold))` всегда истинно → на паузе
   терялся удерживающий момент (риск ухода Z). Заменено на `&&`.
3. **Переполнение буфера в `sd_get_current_filename()`.** `SDCard.cpp`: `strcpy` без границ в
   `char[50/60]` вызывающих; срабатывало в т.ч. на каждый `?`-статус во время печати при
   длинном имени/пути. Сигнатура → `(char* name, size_t cap)` + `snprintf`; все 3 вызова
   (`Protocol.cpp` ×2, `Report.cpp`) передают `sizeof`.
4. **Гонка/overflow TX-буфера WebUI-сокета** (активирована нашим включением `SERIAL2SOCKET_OUT`).
   `Serial2Socket.cpp`: `write()` звался из нескольких задач и вместе с `handle_flush()` дёргал
   нереентерабельный `broadcastBIN` без синхронизации. Теперь TX-буфер под коротким `portMUX`,
   аппенд ограничен (нет записи за границу), `broadcastBIN` — вне критической секции и только из
   `clientCheckTask`.

Проверка: `pio run -e mks_dlc32_v2_1` SUCCESS (Flash 54.8%); `pio test -e native` 5/5 PASSED.
Поведение требует подтверждения на железе.

## 🟡 Отложено / задокументировано (не исправлено намеренно)

- ~~**`notCycleOrHold()` тавтология**~~ — **исправлено** (PR #3). Функция содержала
  `state == Cycle && state == Hold`, то есть практически всегда false (`sys.state` volatile, так что
  в узком окне перехода Cycle→Hold могла вернуть true и отвергнуть команду). Шесть read-only команд
  (`$$`, `$+`, `$L`, `$S`, `$SC`, `$CMD`) полагались на эту опечатку. Намерение выражено явно:
  checker заменён на `anyState`, сломанная функция удалена. Поведение не изменилось.
  Примечание к прежнему обоснованию: SD-гейт (`SDJobPolicy.cpp`) пропускает из этой шестёрки только
  `$$`, а G4-тест ниже шёл в состоянии `Idle` — то есть прохождение при Cycle он не доказывал.
- **Неаутентифицированный доступ по сети** (`ENABLE_AUTHENTICATION` выкл). Включив WebUI-канал, мы
  сделали живым удалённое исполнение G-кода/jog/настроек без пароля для всех в зоне AP
  (`MKS_DLC`/`12345678`). Рекомендация: сменить пароль AP (в WebUI) или включить аутентификацию.
  Realtime `0x18`/FeedHold с сокета тоже доходят (семантика GRBL).
- **После USB-прошивки новой 8 МБ-таблицы переехал SPIFFS** (`0x390000` → `0x610000`) → ассеты WebUI
  оказываются вне новой области, нужно залить их заново (`pio run -t uploadfs` либо образ/скрипт,
  уже содержащий SPIFFS). Ошибки при этом не будет: `WifiServices.cpp:63` вызывает `SPIFFS.begin(true)`
  и молча форматирует пустую область. NVS (настройки/Wi-Fi) НЕ теряется (стабильный offset `0x9000`).
- ~~**`readFileLine` обрезает строку и трактует как EOF**~~ — **исправлено** (PR #3). Оказалось хуже описанного: (а) граница срабатывала уже на 255 символах, а не «>255»;
  (б) `protocol_main_loop` трактовал такой false как успешный финал и печатал `SD Print Finish!`
  посреди файла; (в) терминатор писался после цикла без проверки — последняя строка ровно в 255
  символов без LF давала `line[255] = '\0'` за границей `char fileLine[255]`; (г) `File::read()`
  возвращает `int` и `-1` на ошибке, а результат сразу приводился к `char`.
  Теперь `SDLineResult {Line, Eof, TooLong, ReadError}`, место под `'\0'` резервируется при записи,
  ошибка чтения детектируется, а все четыре активных вызывающих (`protocol_main_loop`, `showSDFile`,
  `runSDFile`, `mks_run_frame`) считают нормальным завершением только `Eof`.
- ~~**Язык интерфейса `=` вместо `==`**~~ — **исправлено** (PR #3). Присваивания убраны,
  `mc_language_init()` заполняет единственную существующую (английскую) таблицу явно; из
  `mks_grbl_parg_init()` удалён блок чтения `$40`, в котором ветка Deutsch была недостижима
  (повторное `== 1` вместо `== 2`). Код не был мёртвым, как считалось: цепочка
  `Grbl_Esp32.ino:28 → _mc_task_init() → mks_grbl_parg_init() → set_language(1)` выполняется
  при каждом старте. **Остаётся:** экранные обработчики выбора языка по-прежнему сохраняют `$40=0/2`
  и подсвечивают выбранную кнопку, хотя строки всегда английские — для конфигурации без экрана
  не имеет значения, не трогали.
- **`board_build.flash_size`** в `ini` — проверено: заголовок образа формирует
  `board_upload.flash_size` (`espressif32@6.12.0`, `builder/main.py:322` — `board.get("upload.flash_size")`).
  `firmware.bin` начинается с `e9 05 03 3f` → 8 MB / 80 МГц / DOUT, то есть результат корректен;
  ключ `board_build.flash_size` не читается и остаётся лишним.

## ❌ Отсеяно как ложные (адверсариальная верификация)

- «SD-код выключен `#undef`-ом» — НЕВЕРНО (см. контекст выше, SD жив).
- Удаление `set_sd_state(Idle)`-recovery — безопасно (терминальные пути закрывают файл).
- Классификатор видит полную строку; гейт таргетит правильный клиент; realtime/ответы доходят до WebUI.
- mDNS-в-AP, порядок `setHostname`, `setAutoReconnect` — корректны (последний — no-op, флаг и так true).
- Гонка на RX-кольце Serial2Socket — нет (push/read в одной задаче).
- `lib_deps` Adafruit MPR121 при OFF — не баг (LDF/`--gc-sections` выкидывают, 0 байт).
- Lowercase-include в `language_ch.h` — мёртв под include-guard, сборку не ломает.

---

# Перепроверка (второй проход)

Повторное многоагентное ревью кумулятивного диффа `335a60a..HEAD` (7 линз ×
3 рефутера на находку). Прогон частично пострадал от обрывов соединения и лимита
сессии: линзы sd-gate/sd-policy/extboard/sweep не завершились. Компенсация:
sd-gate и sd-policy были главным фокусом ПЕРВОГО прохода (+ нативные тесты),
extboard перепроверен вручную (сборки OFF/ON по символам в elf, GitNexus по
вызывающим `sd_get_current_filename`).

## ✅ Исправлено (коммит второго прохода)

1. **HIGH, use-after-free: `broadcastBIN` по висячему `_web_socket` после
   `Web_Server::end()`.** `detachWS()` не вызывался нигде; `end()` делал
   `delete _socket_server`, а указатель в Serial2Socket жил. Сценарий: выключение
   Wi-Fi с экрана/`$Radio/Enabled` → `wifi_services.end()` → delete → следом
   `grbl_send(CLIENT_ALL, "[MSG:WiFi Off]")` буферизует байты → flush по
   освобождённой куче → LoadProhibited/перезагрузка (обрыв задания, если резка шла
   с USB). Взведено нашим включением `SERIAL2SOCKET_OUT`. Фикс: `Serial2Socket.detachWS()`
   в `Web_Server::end()` ДО delete; attach/detach обнуляют буфер под мьютексом.
2. **Потеря хвоста ответов >1200 байт (drop-on-overflow в `write()`)** — ломало наш
   же фикс #25: ответ `$$` для вкладки настроек (2–3 КБ) выдаётся protocol-задачей
   быстрее, чем clientCheckTask успевает флашить (тик 1 мс) → хвост дропался.
   Перепроектирован TX-путь: один FreeRTOS-мьютекс сериализует буфер, отправку и
   attach/detach; при заполнении `write()` флашит сам под локом — потерь нет.
   Рекурсии нет: из колбэков сокета идёт только `grbl_send(CLIENT_SERIAL)` → Uart0
   (проверено по `client_write`). Это же закрыло гонку attachWS без лока.
3. **`setAutoReconnect(true)` был no-op** — в arduino-esp32 1.0.6 флаг по умолчанию
   и так `true` (WiFiSTA.cpp:72), а обработчик disconnect-событий ядра вообще не
   реконнектит причины `AUTH_FAIL` и коды <200 (WiFiGeneric.cpp:405-410) — т.е.
   «реконнекта» наша правка не добавляла. Заменено на явный retry:
   `WiFiConfig::handle()` в STA-режиме пинает `WiFi.reconnect()` каждые 15 с, пока
   нет коннекта (во время первичного коннекта handle() не зовётся — конфликтов нет).
4. **mDNS в AP: имя анонсировалось, но HTTP-сервис нет** — `MDNS.addService` в
   `Web_Server::begin()` был под `WIFI_STA`-only; расширено на AP (согласовано с
   нашим включением `MDNS.begin` в AP в WifiServices). Теперь discovery
   `_http._tcp` видит устройство и в режиме точки доступа.
5. **`pio test` без `-e native` падал** — голая команда подхватывала нативный тест
   на embedded-env (`default_envs`) и не находила `SDJobPolicy.h`. Добавлен
   `test_ignore = test_sd_job_policy` в `[esp32_common]`.

## ❌ Отсеяно вторым проходом

- OTA-миграция таблицы разделов со старой 4MiB-разметки — латентное ограничение
  ESP32 OTA (espota пишет только app), не баг наших правок; первая прошивка 8МБ-таблицы
  делается по USB — уже задокументировано в FORK_NOTES.
- Утечка дубликата WiFi-колбэка при повторных `MDNS.begin()` — механизм в ядре 1.0.6
  реален (ESPmDNS не снимает onEvent), но это framework-уровень, копейки памяти и
  только при ручных переключениях режима Wi-Fi; существовало и до нас в STA.

Проверка: сборки `mks_dlc32_v2_1` (OFF и ON по символам elf) и `_ota` зелёные,
`pio test -e native` 5/5, голый `pio test` больше не падает.

---

# Валидация на железе (реальная плата MKS DLC32 v2.1)

Чип: ESP32-D0WD rev1, flash 8 МБ подтверждён (`esptool flash_id`). Перед прошивкой
снят полный бэкап заводской прошивки: `backup/stock_flash_8MB_<MAC>.bin`
(восстановление: `esptool write_flash 0 <файл>`).

## 🐞 Баг, найденный ТОЛЬКО на железе (исправлен)

**Конкурентный `WiFi.reconnect()` вешал clientCheckTask.** Наш retry в
`WiFiConfig::handle()` исполняется в clientCheckTask, а `StartSTA/ConnectSTA2AP` —
в protocol-задаче. Сценарий: radio OFF (~4 c) + фаза коннекта при ON (~10 c)
превышали 15-секундный интервал → `WiFi.reconnect()` стрелял ПАРАЛЛЕЛЬНО активному
подключению → конкурентные вызовы esp_wifi блокировали clientCheckTask навсегда →
переставал обрабатываться ВЕСЬ ввод (USB/Telnet/HTTP), хотя протокол-задача жила.
При обычной загрузке не проявлялось (millis() < интервала). Фикс: `sta_connect_busy`
(RAII-guard в StartSTA/mks_StartSTA) — пока идёт подключение, retry запрещён и
таймер обновляется. После фикса 3 цикла `$Radio/State=OFF/ON` подряд — плата жива.

## ✅ Проверено end-to-end

| Тест | Результат |
|---|---|
| Загрузка, оси XYZ/шпиндель/концевики/probe | ✅ конфиг применился |
| USB serial: `$I`, `$$`, realtime `?` | ✅ |
| AP-режим: `MKS_DLC` 192.168.4.1 + mDNS в AP (наш фикс) | ✅ `[MSG:Start mDNS ...]` |
| STA: подключение к домашней сети | ✅ (Wi-Fi только WPA2 2.4ГГц; WPA3-only сеть ESP32 не берёт — ограничение чипа/ядра 1.0.6) |
| mDNS с хоста: `mks-dlc32.local` → IP | ✅ (наш hostname) |
| HTTP WebUI (index 170КБ из SPIFFS) | ✅ HTTP 200 |
| Telnet :23 — `$I`, realtime `?` | ✅ |
| WebSocket :81 + HTTP `/command` → `$$` целиком (49 настроек + ok) | ✅ **issue #25 закрыт** |
| Стресс: 4 команды подряд по WS — все ответы полные | ✅ lossless TX подтверждён |
| **UAF-тест**: 2× radio OFF/ON с подключённым WS-клиентом | ✅ нет краша (до фикса — детерминированный UAF) |
| Стресс: 3× radio OFF/ON, `$I`+`?` после каждого | ✅ после фикса sta_connect_busy |
| **OTA по воздуху** (espota → :3232), загрузка из ota_1 | ✅ 51 с, otadata seq=1, STA переподключился |
| SD-карта: детект, листинг, HTTP-upload на SD (`/upload`) | ✅ 16ГБ FAT32 (32ГБ/exFAT не берёт — ограничение ядра 1.0.6 + детект GPIO39) |
| **SD-печать + 2-й интерфейс** (`$SD/Run` c USB, опрос по Telnet) | ✅ см. ниже |

## SD↔USB фича — протокол испытания (G4-файл, 40 строк)

- `?` с Telnet во время печати → `<Idle|...|SD:20.00,/TEST_DWELL.NC>` — прогресс виден ✅
- `$$` с Telnet во время печати → **все 49 настроек + ok** (read-only пропущен гейтом) ✅
- `G0 X1` с Telnet → `error:120` (AnotherInterfaceBusy), движение отклонено ✅
- статус после отклонённого G0 → `SD:57.50` — **печать продолжилась, не оборвалась**
  (регрессия из первого ревью реально починена) ✅
- `$G` с Telnet → parser state + ok ✅; `?` по USB параллельно → SD:70.00 ✅
- финал: `SD Print Finish!`, все 40 строк, статус Idle без SD-поля ✅

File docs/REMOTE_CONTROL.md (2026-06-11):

# Удалённое управление: токен станка + адрес сервера + имя станка

Фича для работы парка станков через центральный сервер. Вместо того чтобы сервер
искал платы в локальной сети, **плата сама устанавливает исходящее TCP-соединение
к серверу** и первой строкой отправляет авторизационные данные (токен станка,
человекочитаемое имя, MAC). Дальше канал работает как обычная telnet-сессия GRBL:
сервер шлёт любые команды (G-код, `$`-команды, realtime `?` / `!` / `~`),
плата отвечает в этот же сокет.

## Параметры (хранятся в NVS, переживают перепрошивку и перезагрузку)

| Параметр | Команда GRBL (terminal/telnet/USB) | Команда ESP (WebUI/HTTP) | Формат |
|---|---|---|---|
| Адрес сервера | `$Remote/Server=192.168.1.50:9000` | `[ESP150]192.168.1.50:9000` | `host:port`, хост — IP или DNS-имя |
| Токен станка | `$Remote/Token=eyJhbGciOi...` | `[ESP151]eyJhbGciOi...` | произвольная строка до 250 символов (JWT помещается) |
| Имя станка | `$Remote/Name=Frezer ceh 2` | `[ESP152]Frezer ceh 2` | до 64 символов, **только латиница/цифры/пробелы** (байты ≥0x80, т.е. кириллицу, ядро GRBL съедает как realtime-команды); не использовать `,` и `]` (сломают разбор hello) |

- Имя станка — чисто для человекочитаемости: оператор по нему понимает, что это
  за станок. Плата его не интерпретирует, просто предъявляет серверу в hello.
- Посмотреть текущее значение: `$Remote/Server` / `$Remote/Token` / `$Remote/Name`
  без `=` (или `[ESP150]` / `[ESP151]` / `[ESP152]`).
- Выключить функцию: задать пустой адрес — `$Remote/Server=`.
- Команды можно отправлять по любому каналу: USB-serial, telnet (порт 23), WebUI-терминал,
  HTTP (`http://<ip>/command?plain=[ESP150]host:port`).
- Изменения подхватываются на лету: адрес читается перед каждой попыткой подключения,
  перезагрузка не обязательна (если соединение уже установлено со старым адресом —
  разорвать его со стороны сервера или перезагрузить плату).
- ⚠️ Лимит длины строки команды GRBL — 256 символов, поэтому через `$Remote/Token=...`
  влезает токен до ~240 символов. Реальный предел значения — 250.

## Протокол подключения

1. Плата подключена к Wi-Fi (режим STA). Если задан `Remote/Server`, она пытается
   открыть TCP-соединение к серверу (таймаут 2 с, повтор каждые 15 с — и после обрывов тоже).
2. Сразу после установки соединения плата отправляет одну строку:

   ```
   [HELLO:token=<значение Remote/Token>,name=<значение Remote/Name>,mac=<MAC платы>]\r\n
   ```

   По `token` сервер аутентифицирует/детектит станок, `name` — человекочитаемое
   имя для отображения оператору, `mac` — уникальный идентификатор железа
   (полезно при дублировании токена).
3. Затем (если включён welcome) придёт стандартный баннер GRBL (`Grbl 1.x ...`).
4. Дальше — полный двусторонний обмен как в telnet: сервер пишет команды строками,
   плата отвечает `ok`/`error:N`/отчётами. Статус запрашивается символом `?`
   (без перевода строки), ответ — `<Idle|MPos:...>`.

В прошивке соединение занимает один из `TELNET_CLIENTS_TOTAL` (3) клиентских слотов,
поэтому работает весь существующий конвейер ввода/вывода GRBL без изменений.
Локальный входящий telnet и WebUI продолжают работать параллельно.

## Сообщения платы (видны во всех подключённых консолях)

- `[MSG:REMOTE Connected to host:port]` — соединение установлено, hello отправлен;
- `[MSG:REMOTE Disconnected]` — связь потеряна, начались повторные попытки;
- `[MSG:REMOTE Bad server address, expected host:port]` — адрес не парсится (нет `:порт`).

Неудачные попытки подключения (сервер недоступен) не логируются, чтобы не засорять консоль.

## Обнаружение плат без настроек: UDP-маячок

Пока `$Remote/Server` **пуст**, плата каждые 5 секунд шлёт UDP-broadcast
(255.255.255.255) на порт **33333**:

```
[DISCOVER:mac=D4:E9:F4:CD:D3:D0,ip=192.168.1.53,name=,fw=grbl1.1-2022042101]
```

- `mac` — уникальный идентификатор железа; `ip` — куда слать команды провижининга;
  `name` — имя станка, если уже задано; `fw` — версия прошивки.
- Как только адрес сервера записан — маячок замолкает, плата переходит на
  постоянное TCP-подключение. Сотрёшь адрес (`$Remote/Server=`) — маячок вернётся.
- Broadcast не выходит за пределы подсети: сервер (или его агент) должен быть
  в одной L2-сети с платами.

Проверено на плате end-to-end: маячок идёт ровно раз в 5 с; после провижининга
по HTTP (`[ESP151]` токен → `[ESP152]` имя → `[ESP150]` адрес) плата подключилась
к серверу в ту же секунду, hello пришёл с новыми токеном и именем, маячок замолчал.

## Инструкция для серверной реализации

Сервер состоит из трёх частей: слушатель маячков, провижининг, основной TCP-сервер.

### 1. Слушатель маячков (UDP :33333)

Слушать UDP-порт 33333, парсить строку `[DISCOVER:k=v,k=v,...]`, складывать
в список «новые станки» по ключу `mac` (пакеты повторяются каждые 5 с —
дедуплицировать). Станок, переставший маячить > 15 с, считать ушедшим из сети.

```python
import socket, re

def listen_discovery():
    s = socket.socket(socket.AF_INET, socket.SOCK_DGRAM)
    s.setsockopt(socket.SOL_SOCKET, socket.SO_REUSEADDR, 1)
    s.bind(('0.0.0.0', 33333))
    while True:
        data, addr = s.recvfrom(512)
        m = re.match(rb'\[DISCOVER:(.+)\]', data)
        if m:
            fields = dict(p.split(b'=', 1) for p in m.group(1).split(b','))
            yield {k.decode(): v.decode() for k, v in fields.items()}
```

### 2. Провижининг (HTTP к плате)

Когда админ одобряет новый станок, сервер по `ip` из маячка записывает настройки
обычными HTTP-запросами (порядок важен: адрес сервера — последним, после него
плата сразу уходит в TCP-режим):

```python
import requests, urllib.parse

def provision(ip, token, name, server_addr):
    for cmd in (f'[ESP151]{token}', f'[ESP152]{name}', f'[ESP150]{server_addr}'):
        r = requests.get(f'http://{ip}/command',
                         params={'commandText': cmd}, timeout=5)
        assert r.ok
```

Через ≤15 секунд плата сама установит TCP-соединение и пришлёт hello с выданным токеном.

### 3. Основной TCP-сервер

Слушать TCP-порт из `Remote/Server`. На каждое входящее соединение:

1. Прочитать первую строку — `[HELLO:token=...,name=...,mac=...]`.
   Токен не найден/отозван → закрыть соединение (плата переподключится через 15 с —
   не банить по IP, просто не обслуживать).
2. Привязать соединение к станку из БД по токену. Дальше это обычная
   GRBL-сессия (как telnet):
   - **строчные команды** (`G0 X10`, `$H`, `$ESP220]/file.gcode`…) — отправлять
     с `\n`, ждать `ok` либо `error:N` на каждую;
   - **realtime-байты без перевода строки**: `?` — статус, `!` — пауза, `~` —
     продолжить, `0x18` (Ctrl-X) — сброс. Ответ на `?`:
     `<Idle|MPos:0.000,0.000,0.000|FS:0,0>` (во время задания с SD добавляется
     поле `SD:проценты,/имя_файла`);
   - плата может слать **асинхронные строки** (`[MSG:...]`, статусы) в любой
     момент — парсер должен быть построчным и не привязанным к «запрос-ответ».
3. Соединение умерло (TCP timeout/EOF) — просто ждать реконнекта: плата
   восстанавливает связь сама каждые 15 с и шлёт hello заново. Рекомендуется
   слать `?` раз в 2–5 с как keepalive и для живого статуса.

Рекомендации:
- держать по станку **одну** сессию: новое соединение с тем же токеном —
  закрыть старое (после обрыва питания платы старый сокет может висеть до TCP-таймаута);
- очередь команд на станок — последовательная: следующую слать после `ok`/`error`
  предыдущей (исключение — realtime-байты, их можно слать всегда);
- загрузка G-code файлов — НЕ через этот сокет, а по HTTP `/upload`
  (см. раздел ниже), запуск — командой `[ESP220]/имя.gcode` уже через сокет.

## Минимальный сервер для проверки (netcat)

```bash
nc -l -p 9000        # ждём; плата сама подключится в течение ~15 с
# увидим: [HELLO:token=...,mac=...]
# вводим: ?            → ответ <Idle|...>
# вводим: $G           → модальные группы, ok
```

## Загрузка G-code файлов на SD-карту

Файлы заливаются по HTTP (тот же эндпоинт, что у WebUI и Android-приложения):

```bash
curl "http://<ip-платы>/upload?path=/" -F "path=/" \
     -F "myfile=@job.gcode;filename=/job.gcode"
# запуск:  [ESP220]/job.gcode  (через сокет или /command?commandText=...)
```

Важные ограничения (проверено на плате):

- **Во время выполнения задания с SD загрузка блокируется намеренно** — карта
  занята чтением исполняемого G-code, запись оборвала бы рез. Заливать файлы
  до запуска задания; после завершения загрузка снова работает. Сейчас плата
  при этом обрывает соединение без ответа (а не отдаёт `Busy`) — учитывать
  в клиенте.
- Карта — **только FAT32** (exFAT не монтируется; карты >32 ГБ из магазина
  обычно exFAT — переформатировать).

## Замечания по безопасности

Канал — голый TCP без TLS (как и стоковый telnet): токен передаётся открытым текстом.
Для работы через интернет закрывать трафик на уровне сети (VPN/WireGuard до сервера)
или держать сервер в той же локалке. JWT можно валидировать на сервере по подписи —
плата его не интерпретирует, просто хранит и предъявляет.

## Реализация (для разработчиков)

- `src/WebUI/RemoteClient.{h,cpp}` — модуль исходящего подключения (новый);
- `src/WebUI/WebSettings.{h,cpp}` — настройки `Remote/Server` (ESP150), `Remote/Token` (ESP151),
  `Remote/Name` (ESP152);
- `src/WebUI/TelnetServer.{h,cpp}` — `attach_client()` сажает исходящий сокет в свободный
  telnet-слот; слоты теперь инициализируются даже при `$Telnet/Enable=0`;
- `src/WebUI/WifiServices.cpp` — begin/handle/end модуля в жизненном цикле Wi-Fi-сервисов.

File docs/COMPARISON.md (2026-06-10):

# Сравнение: наш форк vs сток MKS vs FluidNC

Контекст: плата **MKS DLC32 v2.1** (ESP32, 8 МБ flash), экран TS35 **не используется**,
основной клиент — самописное Android-приложение (`app-release.apk`, Flutter, исходников нет),
которое сейчас работает со стоковой прошивкой `V2.10_H35_2022_0621_N_ZX_001`.
Дата сравнения: июнь 2026.

## Кандидаты

| | Наш форк | Сток MKS (V2.10 → V2.30) | FluidNC |
|---|---|---|---|
| База | Grbl_ESP32 1.1 + MKS + IDLEVEL + наши фиксы | Grbl_ESP32 1.1 + MKS (closed-source сборки) | Наследник Grbl_ESP32, переписан |
| Версия | main (июнь 2026) | V2.30 = **последняя**, 2022-12-23 | **v4.0.3, апрель 2026** |
| Развитие | мы сами | ❌ мертво (всё новое — про другую плату DLC32 MAX; в 2025 обновляли только Windows-тулзы) | ✅ активное (релизы каждые 1-2 мес) |
| Исходники | ✅ | ❌ только .bin | ✅ |

## Совместимость с приложением (`app-release.apk`) — ключевой вопрос

Приложение говорит на **ESP3D v2 протоколе**. Извлечено из APK (strings libapp.so) и
**проверено вживую на нашей прошивке**:

| Что делает приложение | Наш форк | Сток V2.10/V2.30 | FluidNC |
|---|---|---|---|
| `HTTP /command?commandText=...` | ✅ проверено | ✅ (родная среда) | ⚠️ есть, но диалект другой |
| Wi-Fi-провижининг `[ESP100/101/110/115]` | ✅ проверено | ✅ | ⚠️ частично переименовано |
| Телнет-порт 8080 (`[ESP131]8080`) | ✅ проверено (порт оставлен 8080) | ✅ | ⚠️ настройка есть, синтаксис другой |
| Raw-телнет: G-код, `?`-статус (`_parseGrblPosition`) | ✅ проверено | ✅ | ✅ (формат статуса совпадает) |
| `HTTP /upload print.gcode` на SD | ✅ проверено | ✅ | ⚠️ другие эндпоинты для SD |
| Запуск с SD `[ESP220]/print.gcode` | ✅ проверено | ✅ | ❌ нет ESP220 ($SD/Run) |
| Прогресс `SD:xx.xx,имя` в статусе | ✅ проверено | ✅ | ⚠️ другой формат поля SD |

Строки `[ESP740] json=yes` / `RELEASESD` в APK — мёртвые ветки кода (ни сток, ни наша
прошивка их не поддерживают — проверено по strings обоих стоковых образов; приложение
при этом со стоком работает).

**Вывод: приложение полностью совместимо с нашей прошивкой** (флоу
загрузка→запуск→прогресс прогнан на железе end-to-end). **С FluidNC оно, скорее всего,
работать НЕ будет** без доработки (нет исходников → доработка невозможна).

## Что нового в стоковых V2.20/V2.30 (vs V2.10) — стоит ли обновлять сток?

По официальному changelog MKS (TS35/Laser/Normal):

- V2.20 (2022-11): UI экрана, оптимизация передачи файлов, переключение Wi-Fi с экрана.
- V2.30 (2022-12): фиксы UI экрана, «не находился Wi-Fi», **отключён Wi-Fi автореконнект**.

Практически всё — про **экран TS35**, который не используется. Автореконнект они
вырезали (у нас — добавлен и проверен). Партиции V2.30: один app-слот 7 МБ, **без OTA**.
**Обновляться на V2.30 смысла нет.**

## Наш форк vs сток V2.10 (что выигрываем, ничего не теряя)

| | Наш форк | Сток V2.10 |
|---|---|---|
| Совместимость с приложением | ✅ (проверено) | ✅ |
| OTA по воздуху | ✅ (2 слота по 3 МБ, проверено) | ❌ (один app-слот) |
| Wi-Fi реконнект при обрыве | ✅ явный retry 15 с | ⚠️ только частичный (ядро), в V2.30 вырезан |
| WebUI | ✅ ESP3D-WEBUI 2.1.3b0, русский, пауза SD, оверрайды | старый 2.1b68, без паузы/части оверрайдов |
| SD + второй интерфейс | ✅ read-only запросы во время задания, движение отклоняется без обрыва | ❌ `AnotherInterfaceBusy` на всё |
| Стабильность | ✅ исправлены: обрыв SD-печати от 2-го интерфейса, потеря удержания в Hold, переполнение буфера имени файла, use-after-free и потеря хвоста в сокете WebUI, зависание clientCheckTask | содержит все эти баги (та же кодовая база) |
| Экран TS35 | код есть (не проверялся) | ✅ основной фокус MKS |
| Готовые бинарники + скрипты прошивки | ✅ release/ | ✅ .bin (полный образ) |

## Наш форк vs FluidNC v4.0.3

| Категория | Наш форк (Grbl_ESP32) | FluidNC |
|---|---|---|
| **Конфигурация** | компайл-тайм хедеры + `$$` NVS; смена пинов = пересборка | **YAML-файл на флеше** — пины/оси/шпиндель меняются без пересборки |
| **Поддержка DLC32 v2.1** | нативная (это прошивка платы) | ✅ официальные конфиги `MKS_DLC32_21_XYZ.yaml` / `v21_laser` (I2S-пины совпадают с нашей платой — сверено) |
| **Кинематики** | Cartesian, CoreXY | + дополнительные (wall plotter и др.) |
| **Шпиндели** | PWM/реле | + **RS485 VFD** (Huanyang и др.), 10V, лазер с компенсацией |
| **Хоуминг** | базовый Grbl | + squaring двумя моторами на ось, гибче настройки |
| **G-код** | Grbl 1.1 | Grbl 1.1 + расширения (выражения/параметры, M62/M63 и др.) |
| **Сеть** | Wi-Fi AP/STA, mDNS, наш реконнект | Wi-Fi AP/STA, mDNS + WebDAV (файлы по сети) |
| **WebUI** | ESP3D-WEBUI 2.1.3b0 (макс. для v2-API) | WebUI v2 или **v3** (с ~3.7.18) |
| **SD + второй интерфейс** | наша фича: read-only во время задания | архитектура «каналов»; в v4.0.2 чинили коллизии SD-доступа (WebUI vs пульт) — зона активной работы |
| **Bluetooth** | да (Grbl_ESP32) | убран в новых версиях (v3.7+ только Wi-Fi/USB) |
| **Приложение пользователя** | ✅ **работает (проверено)** | ❌ почти наверняка нет |
| **Экран TS35** | код есть | ❌ не поддержан |
| **Сообщество** | issues нашего форка | большое: вики, Discord, форумы |

## Вердикт

1. **Для текущей задачи (плата + самописное приложение, без экрана) — наш форк
   оптимален**: приложение работает (доказано на железе), все стоковые баги исправлены,
   есть OTA/новый WebUI/SD+USB — ничего из этого нет ни в стоке, ни (для приложения)
   во FluidNC.
2. **Обновляться на сток V2.30 — незачем**: изменения экранные, реконнект вырезан,
   OTA нет, исходников нет.
3. **FluidNC — кандидат на будущее**, если потребуются: VFD-шпиндель по RS485,
   сложный хоуминг, конфиг без пересборки, WebUI v3, живое сообщество. Цена перехода:
   **приложение перестанет работать** (исходников нет — не доработать), настройка YAML
   заново, и наши MKS-специфичные фиксы там не нужны/не применимы. Откат простой —
   у нас есть полный бэкап стока и `release/` с нашей прошивкой.

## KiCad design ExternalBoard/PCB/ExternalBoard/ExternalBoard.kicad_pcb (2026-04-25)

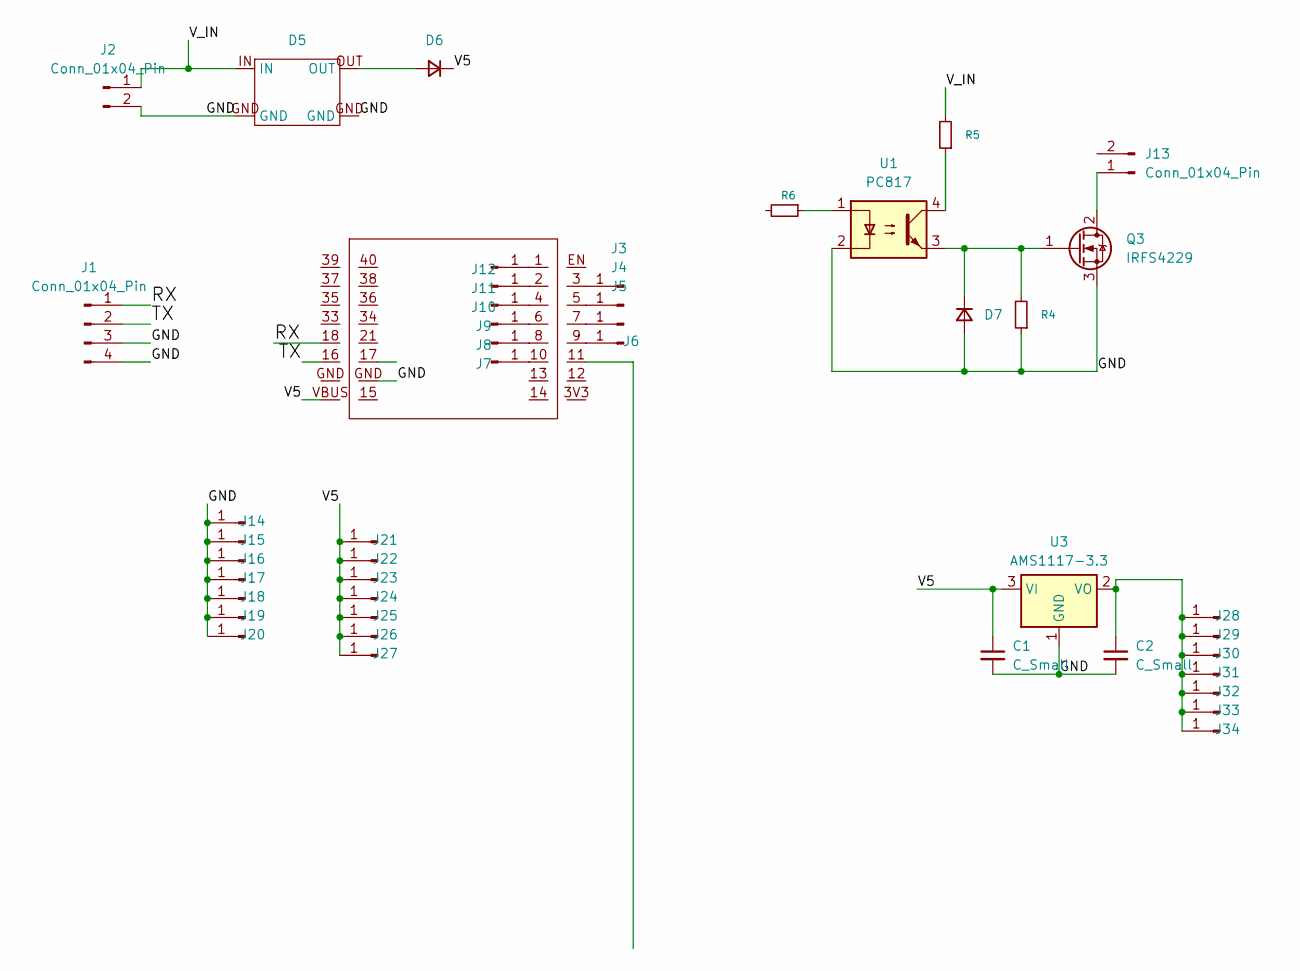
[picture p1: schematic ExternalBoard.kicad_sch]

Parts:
C1, C2: C_Small; C_1206_3216Metric
D1: ESP32_S2_V2
D5: StepDown
D6: D_Small; D_SMA
D7: D_Small; D_SMF
J1: Conn_01x04_Pin; PinHeader_1x04_P2.54mm_Vertical
J2, J13: Conn_01x04_Pin; PinHeader_1x02_P2.54mm_Vertical
J3, J4, J5, J6, J7, J8, J9, J10, J11, J12, J14, J15, J16, J17, J18, J19, J20, J21, J22, J23, J24, J25, J26, J27, J28, J29, J30, J31, J32, J33, J34: Conn_01x04_Pin; PIN0
Q3: IRFS4229; TO-263-2
R4, R5, R6: R_Small; R_1206_3216Metric_Pad1.30x1.75mm_HandSolder
U1: PC817; DIP-4_W7.62mm
U3: AMS1117-3.3; SOT-223-3_TabPin2

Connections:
/GND: C1.2, C2.2, D1.GND, D5.GND, D7.2 (A), J1.3, J1.4, J2.2, J14.1 (Pin_1_1), J15.1 (Pin_1_1), J16.1 (Pin_1_1), J17.1 (Pin_1_1), J18.1 (Pin_1_1), J19.1 (Pin_1_1), J20.1 (Pin_1_1), Q3.3 (S), R4.1, U1.2, U3.1 (GND)
/RX: D1.18, J1.1
/TX: D1.16, J1.2
/V5: C1.1, D1.VBUS, D6.1 (K), J21.1 (Pin_1_1), J22.1 (Pin_1_1), J23.1 (Pin_1_1), J24.1 (Pin_1_1), J25.1 (Pin_1_1), J26.1 (Pin_1_1), J27.1 (Pin_1_1), U3.3 (VI)
/V_IN: D5.IN, J2.1, R5.2
unnamed: D5.OUT, D6.2 (A)
unnamed: D7.1 (K), Q3.1 (G), R4.2, U1.3
unnamed: D1.3, J3.1 (Pin_1_1)
unnamed: D1.5, J4.1 (Pin_1_1)
unnamed: D1.7, J5.1 (Pin_1_1)
unnamed: D1.9, J6.1 (Pin_1_1)
unnamed: D1.10, J7.1 (Pin_1_1)
unnamed: D1.8, J8.1 (Pin_1_1)
unnamed: D1.6, J9.1 (Pin_1_1)
unnamed: D1.4, J10.1 (Pin_1_1)
unnamed: D1.2, J11.1 (Pin_1_1)
unnamed: D1.1, J12.1 (Pin_1_1)
unnamed: J13.1 (Pin_1_1), Q3.2 (D)
unnamed: C2.1, J28.1 (Pin_1_1), J29.1 (Pin_1_1), J30.1 (Pin_1_1), J31.1 (Pin_1_1), J32.1 (Pin_1_1), J33.1 (Pin_1_1), J34.1 (Pin_1_1), U3.2 (VO)
unnamed: R5.1, U1.4
unnamed: R6.1, U1.1

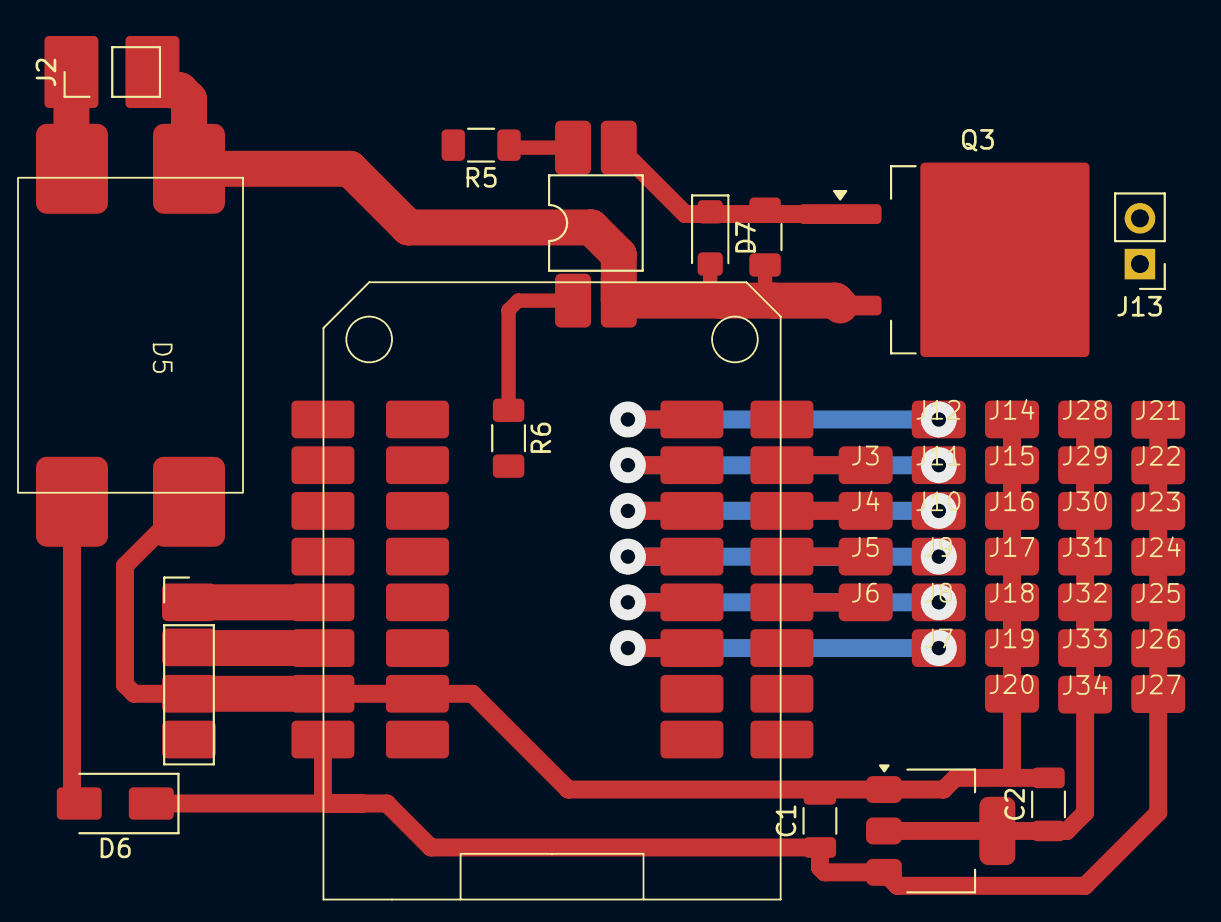
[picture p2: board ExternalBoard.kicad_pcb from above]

Board: 2 copper layers, 46 parts (0 on the bottom side), 21 nets.

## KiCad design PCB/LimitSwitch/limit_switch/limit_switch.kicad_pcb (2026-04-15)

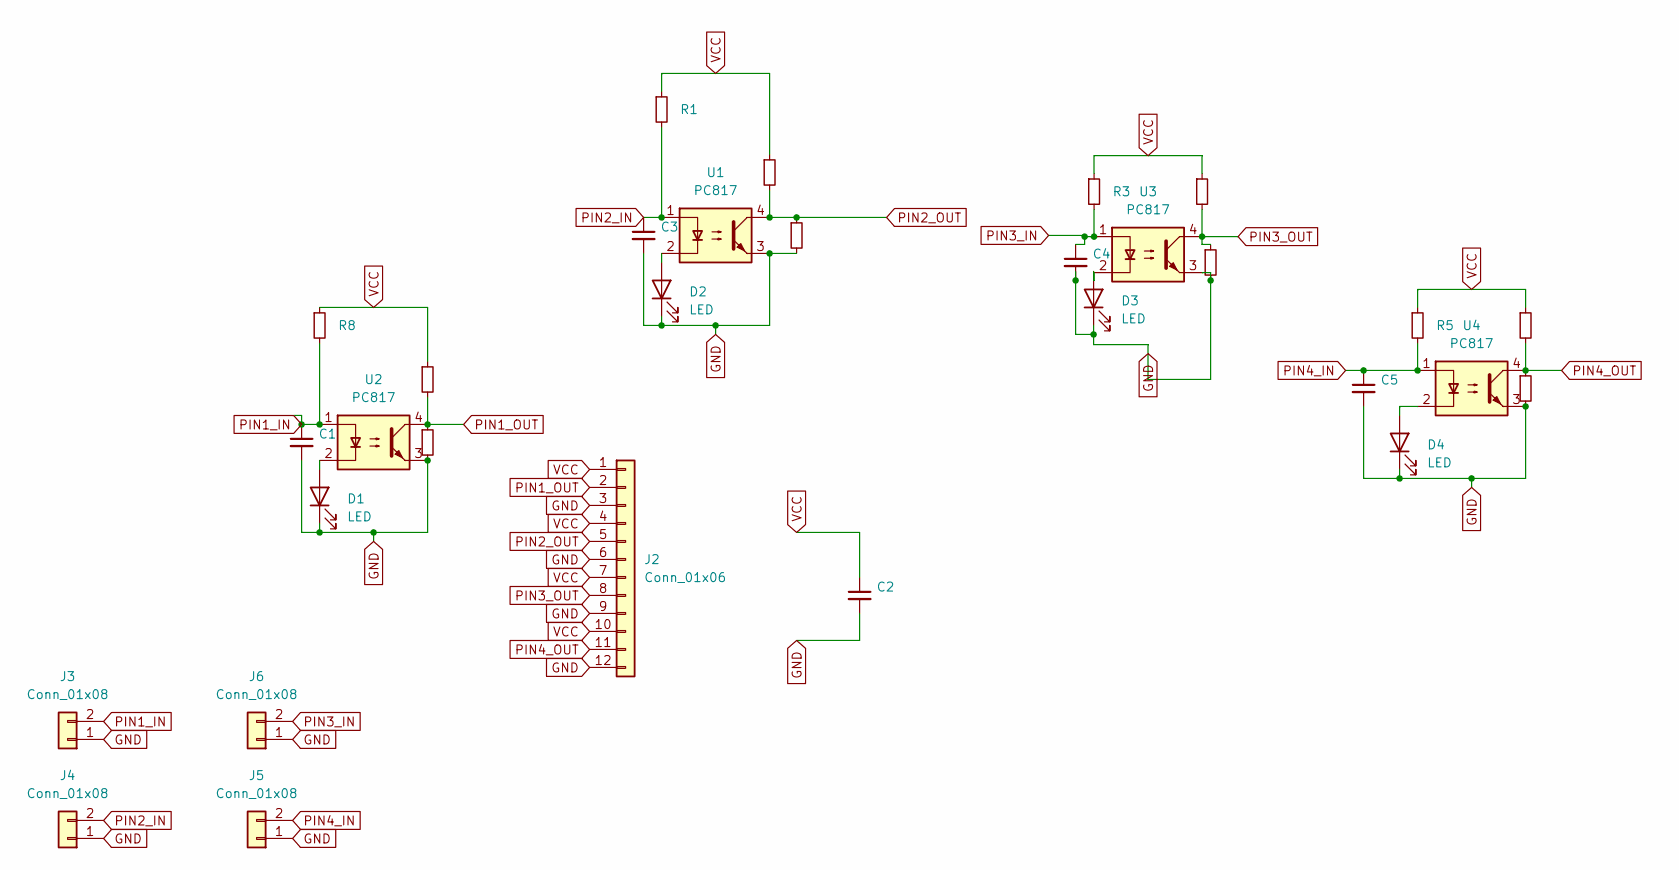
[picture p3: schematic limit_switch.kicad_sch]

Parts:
C1, C2, C3, C4, C5: C_Small; C_1206_3216Metric_Pad1.33x1.80mm_HandSolder
D1, D2, D3, D4: LED; R_0805_2012Metric_Pad1.20x1.40mm_HandSolder
J2: Conn_01x06; PinHeader_1x12_P2.54mm_Vertical
J3, J4, J5, J6: Conn_01x08; PinHeader_1x02_P2.54mm_Vertical
R1, R2, R3, R4, R5, R6, R7, R8, R9, R10, R11, R12: R_Small; R_1206_3216Metric_Pad1.30x1.75mm_HandSolder
U1, U2, U3, U4: PC817; DIP-4_W8.89mm_SMDSocket_LongPads

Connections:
GND: C1.2, C2.2, C3.2, C4.2, C5.2, D1.1 (K), D2.1 (K), D3.1 (K), D4.1 (K), J2.3, J2.6, J2.9, J2.12, J3.1, J4.1, J5.1, J6.1, R7.2, R10.2, R11.2, R12.2, U1.3, U2.3, U3.3, U4.3
unnamed: D1.2 (A), U2.2
unnamed: D2.2 (A), U1.2
unnamed: D3.2 (A), U3.2
unnamed: D4.2 (A), U4.2
PIN1_IN: C1.1, J3.2, R8.2, U2.1
PIN1_OUT: J2.2, R9.2, R12.1, U2.4
PIN2_IN: C3.1, J4.2, R1.2, U1.1
PIN2_OUT: J2.5, R2.2, R7.1, U1.4
PIN3_IN: C4.1, J6.2, R3.2, U3.1
PIN3_OUT: J2.8, R4.2, R10.1, U3.4
PIN4_IN: C5.1, J5.2, R5.2, U4.1
PIN4_OUT: J2.11, R6.2, R11.1, U4.4
VCC: C2.1, J2.1, J2.4, J2.7, J2.10, R1.1, R2.1, R3.1, R4.1, R5.1, R6.1, R8.1, R9.1

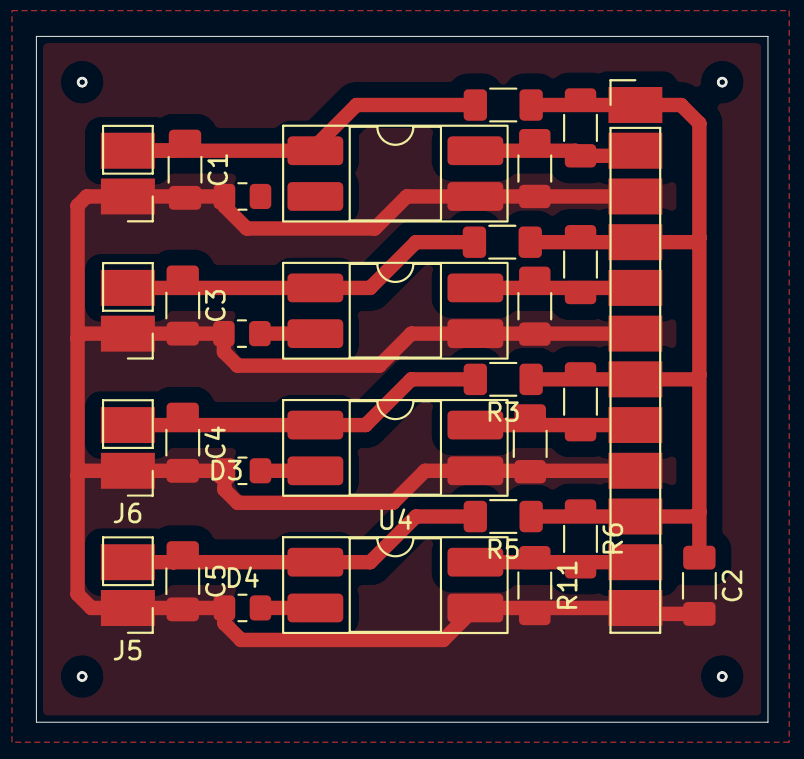
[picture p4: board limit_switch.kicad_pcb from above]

Board: 2 copper layers, 40.6 x 38.1 mm, 30 parts (0 on the bottom side), 14 nets.

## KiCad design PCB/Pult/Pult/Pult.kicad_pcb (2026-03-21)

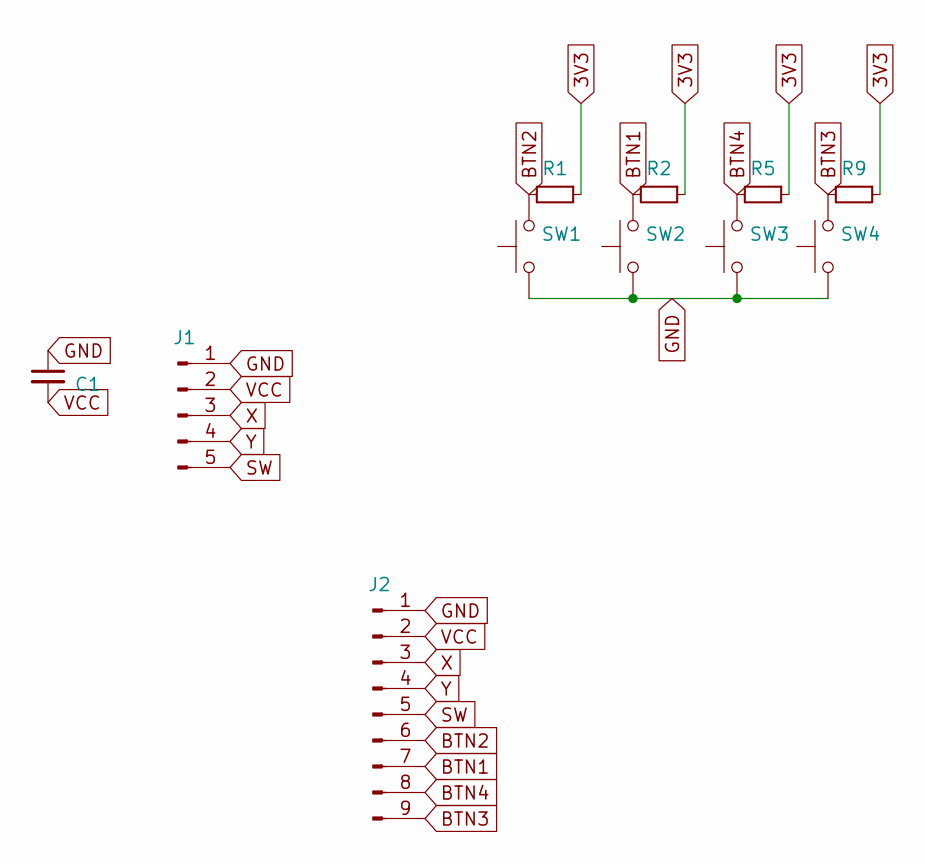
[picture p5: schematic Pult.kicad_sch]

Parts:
C1: C_Small; C_1206_3216Metric_Pad1.33x1.80mm_HandSolder
J1: Conn_01x04_Pin; PinHeader_1x05_P2.54mm_Vertical
J2: Conn_01x04_Pin; PinHeader_1x09_P2.54mm_Vertical
R1, R2, R5, R9: R_Small; R_1206_3216Metric_Pad1.30x1.75mm_HandSolder
SW1, SW2, SW3, SW4: SW_Push; SW_PUSH-12mm

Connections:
3V3: R1.1, R2.1, R5.1, R9.1
BTN1: J2.7, R2.2, SW2.2
BTN2: J2.6, R1.2, SW1.2
BTN3: J2.9, R9.2, SW4.2
BTN4: J2.8, R5.2, SW3.2
GND: C1.1, J1.1, J2.1, SW1.1, SW2.1, SW3.1, SW4.1
SW: J1.5, J2.5
VCC: C1.2, J1.2, J2.2
X: J1.3, J2.3
Y: J1.4, J2.4

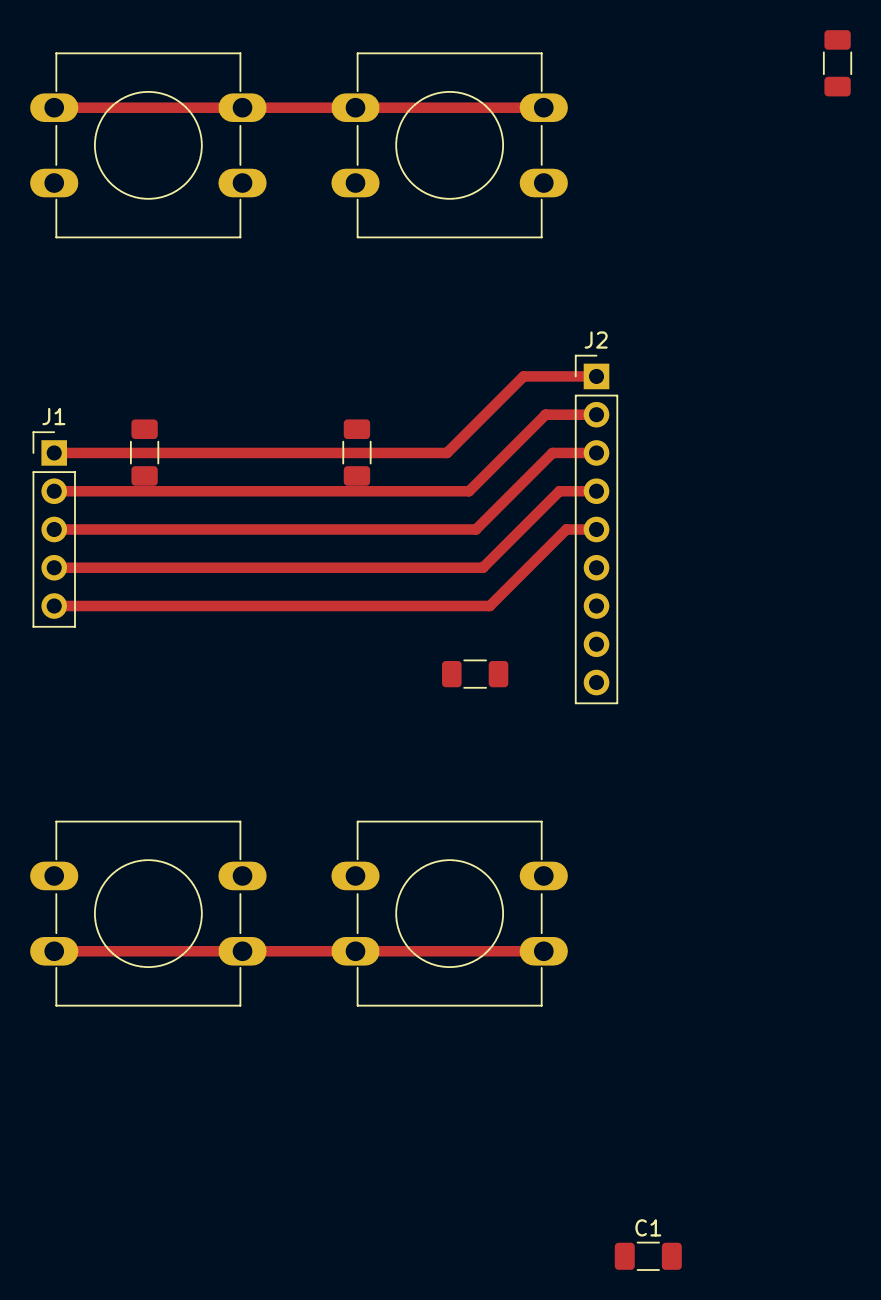
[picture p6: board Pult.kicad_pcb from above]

Board: 2 copper layers, 11 parts (0 on the bottom side), 10 nets.

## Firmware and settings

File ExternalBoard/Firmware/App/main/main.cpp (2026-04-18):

#include <stdio.h>
#include <string.h>

#include "freertos/FreeRTOS.h"
#include "freertos/task.h"
#include "freertos/queue.h"

#include "esp_err.h"
#include "esp_log.h"
#include "esp_intr_alloc.h"

#include "usb/usb_host.h"
#include "usb/hid_host.h"

#include "driver/uart.h"
#include "uart_cmd.h"

#define MIN(a, b) ((a) < (b) ? (a) : (b))

static const char *TAG = "usb_joy_uart";

// ================= UART =================
#define UART_PORT       UART_NUM_1
#define UART_TX_PIN     17
#define UART_RX_PIN     18
#define UART_BAUD_RATE  115200
#define UART_BUF_SIZE   1024

EB_UART_CMD uart_cmd;

static void uart_init_app(void)
{
    const uart_config_t cfg = {
        .baud_rate = UART_BAUD_RATE,
        .data_bits = UART_DATA_8_BITS,
        .parity    = UART_PARITY_DISABLE,
        .stop_bits = UART_STOP_BITS_1,
        .flow_ctrl = UART_HW_FLOWCTRL_DISABLE,
        .source_clk = UART_SCLK_DEFAULT,
    };

    ESP_ERROR_CHECK(uart_driver_install(UART_PORT, UART_BUF_SIZE, 0, 0, NULL, 0));
    ESP_ERROR_CHECK(uart_param_config(UART_PORT, &cfg));
    ESP_ERROR_CHECK(uart_set_pin(
        UART_PORT,
        UART_TX_PIN,
        UART_RX_PIN,
        UART_PIN_NO_CHANGE,
        UART_PIN_NO_CHANGE
    ));
}

uint8_t prev_report[128] = {0};
uint16_t prev_report_len = 0;

static void uart_send_report(const uint8_t *data, size_t len)
{
    if(len == prev_report_len && memcmp(prev_report, data, MIN(len, sizeof(prev_report))) == 0) 
    {
        return;
    }

    uart_cmd.send_cmd(EB_UART_CMD::CMD_INPUT, data, len);
    
    memcpy(prev_report, data, MIN(len, sizeof(prev_report)));
    prev_report_len = len;
}

// ================= APP QUEUE =================
typedef enum {
    APP_EVENT_HID_HOST = 0,
} app_event_group_t;

typedef struct {
    app_event_group_t event_group;
    struct {
        hid_host_device_handle_t handle;
        hid_host_driver_event_t event;
        void *arg;
    } hid_host_device;
} app_event_queue_t;

static QueueHandle_t app_event_queue = NULL;

// ================= USB HOST TASK =================
static void usb_lib_task(void *arg)
{
    const usb_host_config_t host_config = {
        .skip_phy_setup = false,
        .intr_flags = ESP_INTR_FLAG_LEVEL1,
    };

    ESP_ERROR_CHECK(usb_host_install(&host_config));

    // Сообщаем app_main, что USB host уже поднят
    xTaskNotifyGive((TaskHandle_t)arg);

    while (1) {
        uint32_t event_flags = 0;
        esp_err_t err = usb_host_lib_handle_events(portMAX_DELAY, &event_flags);
        if (err != ESP_OK) {
            ESP_LOGE(TAG, "usb_host_lib_handle_events failed: %s", esp_err_to_name(err));
            continue;
        }

        if (event_flags & USB_HOST_LIB_EVENT_FLAGS_NO_CLIENTS) {
            ESP_LOGI(TAG, "No more clients");
            ESP_ERROR_CHECK(usb_host_device_free_all());
            break;
        }
    }

    ESP_LOGI(TAG, "USB host uninstall");
    vTaskDelay(pdMS_TO_TICKS(10));
    ESP_ERROR_CHECK(usb_host_uninstall());
    vTaskDelete(NULL);
}

// ================= HID CALLBACKS =================
static void hid_host_interface_callback(hid_host_device_handle_t hid_device_handle,
                                        const hid_host_interface_event_t event,
                                        void *arg)
{
    uint8_t data[64] = {0};
    size_t data_length = 0;
    hid_host_dev_params_t dev_params;

    ESP_ERROR_CHECK(hid_host_device_get_params(hid_device_handle, &dev_params));

    switch (event) {
        case HID_HOST_INTERFACE_EVENT_INPUT_REPORT:
            ESP_ERROR_CHECK(
                hid_host_device_get_raw_input_report_data(
                    hid_device_handle,
                    data,
                    sizeof(data),
                    &data_length
                )
            );

            // Отправляем HID report в UART1
            uart_send_report(data, data_length);
            break;

        case HID_HOST_INTERFACE_EVENT_DISCONNECTED:
            ESP_LOGI(TAG,
                     "HID disconnected, proto=%d subclass=%d",
                     dev_params.proto,
                     dev_params.sub_class);
            
            ESP_ERROR_CHECK(hid_host_device_close(hid_device_handle));
            uart_cmd.send_cmd(EB_UART_CMD::CMD_INPUT_DISCONNECTED);
            break;

        case HID_HOST_INTERFACE_EVENT_TRANSFER_ERROR:
            ESP_LOGW(TAG,
                     "HID transfer error, proto=%d subclass=%d",
                     dev_params.proto,
                     dev_params.sub_class);
            uart_cmd.send_cmd(EB_UART_CMD::CMD_INPUT_ERROR);
            break;

        default:
            ESP_LOGW(TAG, "Unhandled HID interface event: %d", event);
            break;
    }
}

static void hid_host_device_event(hid_host_device_handle_t hid_device_handle,
                                  const hid_host_driver_event_t event,
                                  void *arg)
{
    hid_host_dev_params_t dev_params;
    ESP_ERROR_CHECK(hid_host_device_get_params(hid_device_handle, &dev_params));

    switch (event) {
        case HID_HOST_DRIVER_EVENT_CONNECTED: {
            ESP_LOGI(TAG,
                     "HID connected, proto=%d subclass=%d",
                     dev_params.proto,
                     dev_params.sub_class);

            const hid_host_device_config_t dev_config = {
                .callback = hid_host_interface_callback,
                .callback_arg = NULL,
            };

            ESP_ERROR_CHECK(hid_host_device_open(hid_device_handle, &dev_config));

            // Для boot-устройств можно переключить в BOOT protocol.
            // Для generic joystick чаще это не требуется, но не мешает только для boot subclass.
            if (dev_params.sub_class == HID_SUBCLASS_BOOT_INTERFACE) {
                ESP_ERROR_CHECK(
                    hid_class_request_set_protocol(hid_device_handle, HID_REPORT_PROTOCOL_BOOT)
                );
            }

            ESP_ERROR_CHECK(hid_host_device_start(hid_device_handle));
            uart_cmd.send_cmd(EB_UART_CMD::CMD_INPUT_CONNECTED);
            break;
        }

        default:
            ESP_LOGW(TAG, "Unhandled HID driver event: %d", event);
            break;
    }
}

static void hid_host_device_callback(hid_host_device_handle_t hid_device_handle,
                                     const hid_host_driver_event_t event,
                                     void *arg)
{
    const app_event_queue_t evt = {
        .event_group = APP_EVENT_HID_HOST,
        .hid_host_device = {
            .handle = hid_device_handle,
            .event = event,
            .arg = arg,
        },
    };

    if (app_event_queue) {
        xQueueSend(app_event_queue, &evt, 0);
    }
}

// ================= MAIN =================
extern "C" void app_main(void)
{
    ESP_LOGI(TAG, "Start USB HID -> UART");

    uart_init_app();
	
	uart_send_report((uint8_t*)"Hello!", 5);

    app_event_queue = xQueueCreate(10, sizeof(app_event_queue_t));
    if (app_event_queue == NULL) {
        ESP_LOGE(TAG, "Failed to create app_event_queue");
        return;
    }

    BaseType_t task_created = xTaskCreatePinnedToCore(
        usb_lib_task,
        "usb_events",
        4096,
        xTaskGetCurrentTaskHandle(),
        2,
        NULL,
        0
    );
    assert(task_created == pdTRUE);

    // Ждём, пока USB host поднимется
    ulTaskNotifyTake(pdFALSE, pdMS_TO_TICKS(2000));

    const hid_host_driver_config_t hid_host_driver_config = {
        .create_background_task = true,
        .task_priority = 5,
        .stack_size = 4096,
        .core_id = 0,
        .callback = hid_host_device_callback,
        .callback_arg = NULL,
    };

    ESP_ERROR_CHECK(hid_host_install(&hid_host_driver_config));

    ESP_LOGI(TAG, "Waiting for HID device...");

    while (1) {
        app_event_queue_t evt;
        if (xQueueReceive(app_event_queue, &evt, portMAX_DELAY)) {
            if (evt.event_group == APP_EVENT_HID_HOST) {
                hid_host_device_event(
                    evt.hid_host_device.handle,
                    evt.hid_host_device.event,
                    evt.hid_host_device.arg
                );
            }
        }
    }
}

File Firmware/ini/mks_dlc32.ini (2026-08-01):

################################################################
# - 	            MKS DLC32 ESP32的默认参数设置
# - CPU Freq:160MHz         - for I2S calc
# - Flash Freq:80MHz        - for ESP32 Flash speed
# - Flash Mode: DOUT        - for ESP32 Flash mode
################################################################
[esp32_common]
platform = espressif32@6.12.0
framework = arduino
board = esp32dev
board_build.f_cpu = 160000000L
board_build.f_flash = 80000000L
board_build.flash_mode = dout
; MKS DLC32 v2.1 несёт ESP32-WROOM-32U с 8 МБ flash
board_upload.flash_size = 8MB
board_build.flash_size = 8MB
build_unflags = -std=gnu++11
monitor_speed = 115200
; нативные unit-тесты гоняются только через `pio test -e native`;
; без этого голый `pio test` пытается собрать их под ESP32 и падает
test_ignore = test_sd_job_policy
extra_scripts =
	post:scripts/copy_boot_app0.py
build_flags = 
	-std=c++17
	-std=gnu++17
	-DCORE_DEBUG_LEVEL=0
	-Wno-unused-variable
	-Wno-unused-function
	-w							
build_src_filter = 
	+<*.h> +<*.s> +<*.S> +<*.cpp> +<*.c> +<*.ino> +<src/>
	-<.git/> -<data/> -<test/> -<tests/>
data_filter = +<*> -<*.bak*> -<*.old*> -<*.tmp*>

; For MKS DLC32
[env:mks_dlc32_v2_1]
platform = ${esp32_common.platform}
extends = esp32_common
board_build.partitions = esp32_8MiB.csv
upload_speed = 460800
build_flags = ${esp32_common.build_flags}
	-D MACHINE_TYPE_DEFAULT
	-D WEBSOCKET_HAS_HEARTBEAT=1
	-D CONFIG_ESP32_ENABLE_COREDUMP=1
	-D CONFIG_ESP32_ENABLE_COREDUMP_TO_FLASH=1
	-D CONFIG_ESP32_COREDUMP_DATA_FORMAT_ELF=1
	-D CONFIG_ESP_COREDUMP_ENABLE=1
	-D CONFIG_ESP_COREDUMP_ENABLE_TO_FLASH=1
	-D CONFIG_ESP_COREDUMP_DATA_FORMAT_ELF=1
lib_ignore = arduinoWebSockets
lib_deps = 
    TMCStepper@>=0.7.0,<1.0.0
	esp32async/AsyncTCP @ ^3.4.10
	adafruit/Adafruit MPR121 @ ^1.2.1
	links2004/WebSockets @ ^2.6.1

[env:mks_dlc32_v2_1_ota]
platform = ${esp32_common.platform}
extends = esp32_common
board_build.partitions = esp32_8MiB.csv
upload_protocol = espota
upload_port = 192.168.1.53
upload_flags = --port=3232
build_flags = ${esp32_common.build_flags}
	-D MACHINE_TYPE_DEFAULT
	-D WEBSOCKET_HAS_HEARTBEAT=1
	-D CONFIG_ESP32_ENABLE_COREDUMP=1
	-D CONFIG_ESP32_ENABLE_COREDUMP_TO_FLASH=1
	-D CONFIG_ESP32_COREDUMP_DATA_FORMAT_ELF=1
	-D CONFIG_ESP_COREDUMP_ENABLE=1
	-D CONFIG_ESP_COREDUMP_ENABLE_TO_FLASH=1
	-D CONFIG_ESP_COREDUMP_DATA_FORMAT_ELF=1
lib_ignore = arduinoWebSockets
lib_deps = 
    TMCStepper@>=0.7.0,<1.0.0
	esp32async/AsyncTCP @ ^3.4.10
	adafruit/Adafruit MPR121 @ ^1.2.1
	links2004/WebSockets @ ^2.6.1

; TMC2209 в UART-режиме: шина на пинах I2C-разъёма (IO0/IO4), coolant отключён
[env:mks_dlc32_v2_1_tmc]
platform = ${esp32_common.platform}
extends = esp32_common
board_build.partitions = esp32_8MiB.csv
upload_speed = 460800
build_flags = ${esp32_common.build_flags}
	-D MACHINE_TYPE_DEFAULT
	-D USE_TMC2209_UART
	-D WEBSOCKET_HAS_HEARTBEAT=1
	-D CONFIG_ESP32_ENABLE_COREDUMP=1
	-D CONFIG_ESP32_ENABLE_COREDUMP_TO_FLASH=1
	-D CONFIG_ESP32_COREDUMP_DATA_FORMAT_ELF=1
	-D CONFIG_ESP_COREDUMP_ENABLE=1
	-D CONFIG_ESP_COREDUMP_ENABLE_TO_FLASH=1
	-D CONFIG_ESP_COREDUMP_DATA_FORMAT_ELF=1
lib_ignore = arduinoWebSockets
lib_deps =
    TMCStepper@>=0.7.0,<1.0.0
	esp32async/AsyncTCP @ ^3.4.10
	adafruit/Adafruit MPR121 @ ^1.2.1
	links2004/WebSockets @ ^2.6.1

; For MKS DLC32 CoreXY
;[env:mks_dlc32_v2_1_CoreXY]
;platform = ${esp32_common.platform}
;extends = esp32_common
;board_build.partitions = Grbl_Esp32/ld/mks_dlc32_partition.csv
;upload_port = COM8
;upload_speed = 921600
;build_flags = ${esp32_common.build_flags}
;			-D MACHINE_TYPE_COREXY
;lib_deps = 
;    TMCStepper@>=0.7.0,<1.0.0

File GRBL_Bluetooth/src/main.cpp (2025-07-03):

#include <stdio.h>
#include <stddef.h>
#include <WiFi.h>
#include <ESPmDNS.h>
#include <ArduinoOTA.h>
#include "BluetoothSerial.h"
#include "ESPTelnet.h"

#if !defined(CONFIG_BT_ENABLED) || !defined(CONFIG_BLUEDROID_ENABLED)
#error Bluetooth is not enabled! Please run `make menuconfig` to and enable it
#endif

#define MKS_Serial Serial2

BluetoothSerial SerialBT;
ESPTelnet Telnet;

void onBtData(const uint8_t *buffer, size_t size)
{
  MKS_Serial.write(buffer, size);
}

char buffer[128];

void onMksData()
{
  int avail_bytes;

  while((avail_bytes = MKS_Serial.available()) > 0)
  {
    auto readed = MKS_Serial.readBytes(buffer, min<int>(avail_bytes, sizeof(buffer)));

    Telnet.write((uint8_t*)buffer, readed);
    SerialBT.write((uint8_t*)buffer, readed);
    Serial.write((uint8_t*)buffer, readed);
  }
}

void onSerialData()
{
   int avail_bytes;

    while((avail_bytes = Serial.available()) > 0)
    {
      auto readed = Serial.readBytes(buffer, min<int>(avail_bytes, sizeof(buffer)));

      MKS_Serial.write((uint8_t*)buffer, readed);
    }
}

void onTelnetData(String data)
{
    MKS_Serial.write((uint8_t*)data.c_str(), data.length());
}

volatile int bt_connection_event = 0;

void Bt_Status (esp_spp_cb_event_t event, esp_spp_cb_param_t *param) {

  if (event == ESP_SPP_SRV_OPEN_EVT) 
  {
    bt_connection_event = 30;
  }
}

const char *ssid = "kv-41";
const char *password = "21302130";

void setup() 
{

  Serial.begin(115200);

  SerialBT.begin("MKS32"); //Bluetooth device name

  MKS_Serial.setPins(26, 27);
  MKS_Serial.begin(115200, SERIAL_8N1);

  SerialBT.onData(onBtData);
  Serial.onReceive(onSerialData);
  MKS_Serial.onReceive(onMksData);
  Telnet.onInputReceived(onTelnetData);

  SerialBT.register_callback(Bt_Status);

  WiFi.mode(WIFI_STA);
  WiFi.begin(ssid, password);

  for(auto i = 0; i < 20; i++)
  {
    if(WiFi.waitForConnectResult() == WL_CONNECTED)
      break;

    delay(100);
  }

  ArduinoOTA
    .onStart([]() {
      String type;
      if (ArduinoOTA.getCommand() == U_FLASH) {
        type = "sketch";
      } else {  // U_SPIFFS
        type = "filesystem";
      }

      // NOTE: if updating SPIFFS this would be the place to unmount SPIFFS using SPIFFS.end()
      Serial.println("Start updating " + type);
    })
    .onEnd([]() {
      Serial.println("\nEnd");
    })
    .onProgress([](unsigned int progress, unsigned int total) {
      Serial.printf("Progress: %u%%\r", (progress / (total / 100)));
    })
    .onError([](ota_error_t error) {
      Serial.printf("Error[%u]: ", error);
      if (error == OTA_AUTH_ERROR) {
        Serial.println("Auth Failed");
      } else if (error == OTA_BEGIN_ERROR) {
        Serial.println("Begin Failed");
      } else if (error == OTA_CONNECT_ERROR) {
        Serial.println("Connect Failed");
      } else if (error == OTA_RECEIVE_ERROR) {
        Serial.println("Receive Failed");
      } else if (error == OTA_END_ERROR) {
        Serial.println("End Failed");
      }
    });

  ArduinoOTA.begin();

  Telnet.begin();   
  
  Serial.println("Ready");
  Serial.print("IP address: ");
  Serial.println(WiFi.localIP());
}


void loop() 
{
  Telnet.loop();

  delay(3);

  ArduinoOTA.handle();

  delay(3);

  if(bt_connection_event > 0)
  {
    bt_connection_event--;

    if(bt_connection_event == 0)
      SerialBT.println(WiFi.localIP());
  }
}

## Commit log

2026-06-08 Fix Linux build, gate external board behind a toggle, repo hygiene
    - ExternalBoard.cpp: fix Windows-only include path "mks\..." -> "mks/..."
    (это единственное, что мешало сборке на Linux/Mac).
    - Gate ExternalBoard.cpp and I2C.cpp behind #ifdef ENABLE_EXTERNAL_BOARD;
    make the flag a master toggle in Config.h, OFF by default. На стоковой
    DLC32 v2.1 пульта MPR121 нет — так не тянется Adafruit_MPR121, не заняты
    GPIO 4/0, экономится flash. Проверено сборкой в обе стороны.
    - Remove committed build artifact Grbl_Esp32.ino.cpp (хардкоженные C:\ пути).
    - Add .gitignore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
2026-06-08 docs: rewrite README and add fork notes/roadmap
    - README: назначение форка, целевое железо (DLC32 v2.1 + TS35), карта пинов,
    сборка, переключатель пульта, статус.
    - docs/FORK_NOTES.md: происхождение, что добавил IDLEVEL, что сделано в форке,
    заметки по плате, дорожная карта (удалёнка/SD↔USB/язык), issues оригинала.
2026-06-08 docs: add board hardware spec (BOARD_SPEC.md), correct OTA flash assumption
    - BOARD_SPEC.md: спецификация MKS DLC32 v2.1 из официальных источников
    (ESP32-WROOM-32U, 8 МБ flash, 520 КБ RAM, 12/24В, TMC2209, без Ethernet — связь по Wi-Fi).
    - Уточнено по всему репо: flash платы = 8 МБ, поэтому OTA-env с esp32_16MiB.csv
    не подходит — нужна OTA-разбивка под 8 МБ. README/FORK_NOTES поправлены.
2026-06-08 OTA: add 8 MB partition table, wire both envs to it
    - Add esp32_8MiB.csv: dual OTA app slots (3 MB each) + SPIFFS for the
    ESP32-WROOM-32U (8 MB flash) on MKS DLC32 v2.1.
    - Point both mks_dlc32_v2_1 (USB) and _ota envs at it; set flash_size = 8MB.
    Прежний OTA-env брал esp32_16MiB.csv, не влезавший в 8 МБ.
    - Drop USE_UART_I2C_PINS from the OTA env (оно уводило консольный Uart0 на
    GPIO0/4, что ломает USB-консоль на стоковой плате).
    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
    [esp32_8MiB.csv]
2026-06-08 wifi: auto-reconnect STA on drop, enable mDNS in AP mode
    - WifiConfig.cpp: WiFi.setAutoReconnect(true) in both STA start paths
    (StartSTA / mks_StartSTA). Раньше при обрыве Wi-Fi станция не переподключалась
    (в WiFiEvent только ставился флаг), что для удалёнки критично.
    - WifiServices.cpp: mDNS теперь стартует и в AP-режиме, не только STA —
    http://<hostname>.local доступен и при подключении к точке самой платы.
    Оба билда зелёные (Flash 54.8%). Требует валидации на реальной плате.
    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
2026-06-08 sd+usb: allow read-only queries from a 2nd interface during SD jobs
    Раньше во время печати с SD char-гейт в Serial.cpp дропал любой ввод с USB/сети
    и слал error:AnotherInterfaceBusy на каждую строку — хост не мог даже опросить
    состояние во время гравировки.
    - SDJobPolicy.{h,cpp}: чистый классификатор line_safe_during_sd_job() — пропускает
    read-only запросы ($$ $# $G $I $N $) и пустые строки, блокирует движение/исполнение
    и запись настроек.
    - Protocol.cpp: на уровне готов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
2026-06-08 webui: fix settings tab hang (#25) — enable Serial2Socket IN/OUT
    Корень зависания вкладки настроек WebUI: ENABLE_SERIAL2SOCKET_IN/OUT были выключены
    в Config.h. GRBL-команды из WebUI ($$, jog, смена hostname) пушились в Serial2Socket,
    но не читались в gcode-буфер (IN, Serial.cpp:166) и ответы не уходили в WebSocket
    (OUT, Serial.cpp:367). Работали только [ESP...] (синхронный HTTP) — поэтому вкладка
    настроек ждала $$ вечно.
    - Config.h: включены ENABLE_SERIAL2SOCKET_IN и ENABLE_SERIAL2SOCKET_OUT
    (реализация Serial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
2026-06-08 review fixes: SD-print abort regression, stepper-hold, filename overflow, socket TX race
    По итогам адверсариального код-ревью (см. docs/CODE_REVIEW.md):
    1. РЕГРЕССИЯ (наша): отклонение/выполнение строки 2-го интерфейса во время SD-печати
    обрывало печать. Protocol.cpp: report_status_message() при BusyPrinting на не-Ok
    делает closeFile() (обрыв), на Ok — двойную прокрутку SD-потока. SD-гейт переписан:
    строки 2-го интерфейса квитируются напрямую (ok/error:N), минуя SD-логи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
2026-06-10 recheck fixes: socket use-after-free + lossless TX, real STA reconnect, AP mDNS service, pio test
    Второй проход ревью (дифф 335a60a..6ccb2b4, 7 линз + адверс. верификация):
    - Serial2Socket: TX-путь на FreeRTOS-мьютексе — flush при заполнении под локом
    (хвост $$ >1200Б больше не теряется), attach/detach атомарны
    - WebServer::end(): detachWS до delete _socket_server (use-after-free при
    выключении/рестарте Wi-Fi -> краш по висячему указателю)
    - WifiConfig: убран no-op setAutoReconnect (в ядре 1.0.6 и так true, AUTH_FAIL
    н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
    [mks_dlc32.ini]
2026-06-10 hw validation: fix clientCheckTask hang from concurrent WiFi.reconnect during StartSTA
    Найдено на реальной плате: retry из WiFiConfig::handle() (clientCheckTask)
    стрелял параллельно активному ConnectSTA2AP (protocol-задача) -> конкурентные
    вызовы esp_wifi вешали clientCheckTask -> умирал весь ввод (USB/Telnet/HTTP).
    Фикс: RAII-флаг sta_connect_busy в StartSTA/mks_StartSTA, retry ждёт окончания.
    Прогнано на железе (ESP32-D0WD, flash 8MB): USB/$$/?, AP+mDNS, STA+mDNS c хоста,
    HTTP WebUI, Telnet, WS+/command $$ целиком (#25), UAF radio-toggle x2 бе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
2026-06-10 docs: SD+USB feature validated on real hardware
    SD-печать (G4-файл) + Telnet одновременно: $$ отдаёт все настройки, G0 -> error:120
    без обрыва печати, прогресс в ?-статусе, SD Print Finish. HTTP-upload на SD работает.
    Карта обязана быть FAT32 (exFAT не поддержан ядром 1.0.6).
2026-06-10 docs: README/FORK_NOTES — статус после валидации на железе
    Роадмап п.1 (удалёнка) и п.2 (SD+USB) закрыты и помечены проверенными на плате;
    README отражает реальное состояние (OTA, реконнект, WPA2-ограничение, FAT32).
2026-06-10 webui: upgrade to ESP3D-WEBUI 2.1.3b0 (SD pause/resume, GRBL overrides, русский)
    Старый билд 2.1b68 от MKS не имел паузы SD и части реалтайм-оверрайдов.
    Новый собран из luc-github/ESP3D-WEBUI ветка 2.1 (gulp@4, --lang grbl),
    заголовок «MKS DLC32 — ESP3D WebUI». Рецепт пересборки в FORK_NOTES.
    Проверено на плате: HTTP 200 (gz 144K), WS-канал жив ($$ 49 настроек + ok).
2026-06-10 release: готовый комплект прошивки по USB для Windows и Linux
    release/: bootloader+partitions+boot_app0+firmware+spiffs(WebUI) + flash_usb.sh/.bat
    + README с инструкцией. Скрипты передают --flash_mode dout --flash_freq 80m
    --flash_size 8MB — без них esptool не патчит заголовок бутлоадера и плата уходит
    в тихий boot-loop (поймано на железе). NVS не трогаем — настройки сохраняются.
    Комплект проверен на плате: прошивка скриптом -> загрузка, STA, WebUI, WS живы.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
2026-06-10 webui: исправлены ссылки в навбаре — Firmware на наш репо, Interface на ветку 2.1
    «Firmware» вело на заброшенный bdring/Grbl_Esp32, «Interface» — на главную
    ESP3D-WEBUI (там уже несовместимый v3 под ESP3D 3.x). Теперь FW -> наш форк,
    UI -> ESP3D-WEBUI/tree/2.1. Обновлены data/index.html.gz и release/spiffs.bin;
    проверено на плате.
2026-06-10 docs: сравнение наш форк / сток MKS V2.10-V2.30 / FluidNC v4.0.3 + совместимость APK
    Разобран app-release.apk (Flutter): протокол = ESP3D v2 (/command, ESP100-220,
    телнет 8080, /upload print.gcode). Флоу приложения прогнан на нашей прошивке
    вживую — полностью совместим; ESP740/json=yes в APK — мёртвый код (нет и в стоке).
    Сток: V2.30 (2022-12) — последняя для классического DLC32, изменения экранные,
    реконнект вырезан, OTA нет. FluidNC v4.0.3: жив, DLC32-конфиги официаль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
2026-06-10 gitignore: APK, временные bin/gcode в корне, IDE, Python/node, мусор ОС
    release/*.bin остаются отслеживаемыми (игнор только /*.bin в корне).
2026-06-10 release: обновить spiffs/VERSION, добавить единый 8MB-образ и инструкцию
    Свежая сборка main; merged-bin и zip генерируются для GitHub Release (в gitignore).
2026-06-11 feat: удалённое управление — токен, имя станка и адрес сервера в NVS
    Плата сама устанавливает исходящее TCP-соединение к серверу
    ($Remote/Server, ESP150) и первой строкой шлёт авторизационный hello
    с токеном ($Remote/Token, ESP151), именем станка ($Remote/Name, ESP152)
    и MAC. Дальше канал работает как обычная telnet-сессия GRBL.
    Авто-реконнект каждые 15 с, telnet-слоты живут и при $Telnet/Enable=0.
    Инструкция: docs/REMOTE_CONTROL.md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
2026-06-11 fix: краш при старте — Remote_Client::handle() до создания настроек
    clientCheckTask дёргает WifiServices::handle() раньше make_settings(),
    remote_server_address ещё NULL -> LoadProhibited и boot-loop.
    Добавлен guard. Проверено на плате: загрузка чистая, HELLO с токеном
    и именем приходит на сервер, реконнект и NVS-персистентность работают.
    В доке уточнено: имя станка — только латиница (байты >=0x80 ядро GRBL
    перехватывает как realtime-команды).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
2026-06-11 release: v1.1.0 — прошивка с удалённым управлением (токен/имя/сервер)
    Свежая сборка main 828210f, проверена на плате. Merged-bin и zip
    генерируются для GitHub Release (в gitignore).
2026-06-11 docs: загрузка G-code на SD — перепроверка по жалобе заказчика
    HTTP /upload прогнан на плате: малый файл, 1.2 МБ, после старта,
    после SD-задания — везде ок. Единственный падающий сценарий —
    загрузка во время выполнения задания с SD (блокируется намеренно,
    карта занята чтением). Отмечено в README/FORK_NOTES/REMOTE_CONTROL;
    в TODO — отдавать честный Busy-ответ вместо обрыва соединения.
2026-06-11 feat: UDP-маячок обнаружения непрошитых плат + инструкция для сервера
    Пока $Remote/Server пуст, плата раз в 5 с шлёт broadcast на UDP:33333
    [DISCOVER:mac=...,ip=...,name=...,fw=...] — сервер находит платы в сети
    и прописывает токен/имя/адрес по HTTP. Адрес задан -> маячок замолкает.
    В REMOTE_CONTROL.md — полная инструкция серверной реализации: слушатель
    маячков, провижининг, основной TCP-сервер (hello, ok/error, realtime,
    реконнект, очередь кома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
2026-06-11 docs: UDP-маячок провалидирован на плате end-to-end
    Маячок раз в 5 с с верным форматом; провижининг по HTTP
    ([ESP151]->[ESP152]->[ESP150]) -> hello с новыми токеном/именем
    в ту же секунду, маячок замолкает, плата живёт.
2026-06-11 release: v1.2.0 — прошивка с UDP-маячком обнаружения плат
    Сборка main 7664717, маячок и провижининг провалидированы на плате.
    Merged-bin и zip генерируются для GitHub Release (в gitignore).
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2026-07-31 fix(sd,settings): статус чтения строки с SD, anyState для read-only команд, фикс языка
    1) readFileLine (SDCard.cpp) возвращал один boolean на три разных исхода —
    EOF, ошибку чтения и слишком длинную строку. protocol_main_loop трактовал
    любой false как успешный финал и печатал "SD print done" / "SD Print Finish!"
    посреди файла. Плюс терминатор писался после цикла без проверки: последняя
    строка ровно в 255 символов без LF давала line[255] = '\0' за г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
2026-07-31 fix(sd): довести обработку SDLineResult до всех вызывающих + детект ошибки чтения
    Ревью bc7f578: основной SD-путь исправлен, но остальные callers снова
    схлопывали ошибки в успешное завершение.
    - runSDFile (WebSettings.cpp): TooLong/ReadError в первой строке возвращали
    Error::Ok, то есть тихий успех без запуска задания. Теперь Eof -> Ok
    (пустой макрос), TooLong -> LineLengthExceeded, ReadError -> FsFailedRead.
    - showSDFile: оборванный вывод выглядел как полно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
2026-07-31 docs: синхронизировать статус в README и ссылки на коммиты
    README: сняты пункты «🔜 фикс языка», добавлены закрытые — SD-печать больше не
    выдаёт сбой за успешное завершение, язык, anyState, нулевой ток и валидация
    микрошага у Trinamic-драйверов. В CODE_REVIEW/FORK_NOTES ссылки на коммиты
    переписаны под эту линию (cherry-pick из feat/tmc2209-uart меняет SHA).
2026-07-31 fix(sd): централизованная очистка состояния в closeFile + README/доки
    closeFile() при уже невалидном myFile выходил до сброса SDState/SD_ready_next.
    Основной путь печати это компенсировал локально, но showSDFile, runSDFile и
    mks_run_frame результат игнорируют — после выёма карты SD оставался в
    BusyPrinting, и последующие операции получали Busy. Теперь признаки печати
    снимаются в самом closeFile (BusyUploading не трогаем — им владеет WebServer),
    а лок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
2026-07-31 fix(tmc-spi): нулевой ток и валидация микрошага в SPI-драйвере
    Те же два бага, что были в UART-драйвере (69c7ab5), жили и в SPI-варианте:
    rms_current(0) даёт CS=-1 -> 255 -> обрезка до 31, то есть максимальный ток
    вместо выключенного, а microsteps() молча игнорирует значения вне своего
    switch. Сейчас SPI-путь не инстанцируется (блок *_TRINAMIC_DRIVER в
    machine-хедере целиком под #ifdef USE_TMC2209_UART), но грабли остаются
    для любого, кто заведёт TMC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
2026-07-31 fix: гонка myFile, деление на ноль в calc_tstep, нулевой ток в UART-драйвере
    По результатам ревью main@b0452056.
    - sd_get_current_filename() и sd_file_check() читали глобальный myFile без
    sd_file_mux, тогда как closeFile() под ним. ?-статус во время задания идёт из
    protocol-задачи, а тач-«Стоп» закрывает файл из UI-задачи: между проверкой
    if (myFile) и myFile.name() файл успевает закрыться — use-after-free на
    fs::FileImpl. Обе функции взяты под SdFileLock.
    - calc_tstep() вы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
2026-07-31 fix: доводка по ревью — retry рамки, дубль сообщения, override'ы, мелочи
    - mks_run_frame: abort по TooLong/ReadError оставлял is_use_same_file = true,
    и повторный запуск рамки пропускал парсинг — ехал с M3 по частично
    посчитанным границам. Теперь abort сбрасывает флаг, retry парсит заново.
    - readFileLine при невалидном myFile больше не зовёт report_status_message:
    все вызывающие обрабатывают ReadError сами, а report при BusyPrinting ещё
    и закрывал файл —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
2026-08-01 fix(trinamic): Run=0 отключает выход через TOFF=0, а не только IRUN=0
    Ревью поймало: IRUN=0 у TMC2209 — это не «выключено», а 1/32 шкалы тока
    (даташит, IHOLD_IRUN: «Motor run current (0=1/32 … 31=32/32)»), то есть
    ~55 мА RMS при Rsense 0.11. Настоящее отключение — TOFF=0: «Driver
    disable, all bridges off» (CHOPCONF).
    Теперь при $Axis/Current/Run=0 оба драйвера (SPI и UART) пишут TOFF=0
    и обнуляют IRUN/IHOLD; при ненулевом токе чоппер возвращается
    (StealthChop -> TOFF=5, иначе 3 — как в дефолтн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
2026-08-01 fix(review): String через varargs в config_message + мьютекс UART-шины TMC
    pinName() возвращает String — без .c_str() уход в varargs это UB
    (печаталось по случайности раскладки SSO-буфера). Мьютекс сериализует
    транзакции шины: запись настроек ($140/$150/$160) идёт из задачи
    команды, readSgTask при включённом $Report/StallGuard читает регистры
    из своей — без блокировки датаграммы перемешивались.
2026-08-01 fix(tmc): согласование уровней в доках + нулевой ток, микрошаг, SENDDELAY
    Проверка по официальной схеме DLC32 V2.1_003 и даташиту TMC2209 показала,
    что логика шаговой части платы пятивольтовая: VIO сокета жёстко на +5V,
    step/dir/en с 74HC595 @5V, EN подтянут к +5V резисторами R31-R33.
    Поэтому UART нельзя вести напрямую: порог "1" у TMC2209 = 0.7*VIO = 3.5 В,
    а отвечает драйвер уровнем 5 В в GPIO ESP32 (абс. максимум ~3.6 В).
    Документация:
    - раздел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
